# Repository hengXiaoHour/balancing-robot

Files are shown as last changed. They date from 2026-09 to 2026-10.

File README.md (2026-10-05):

# Balancing Robot






Self-balancing two-wheel robot on ESP32 + L298N + MPU IMU, with a serial
setup wizard, WiFi Web UI (telemetry + PID tuning), and optional ESP-NOW
joystick control. Runtime-configurable: pins, WiFi, IMU, and PID all live
in NVS via the serial CLI — `settings.h` holds seed defaults only.

> Built for real hardware: dual angle PID @ 1 kHz, Madgwick fusion, NVS-persisted
> config, embedded Web UI served from flash, OTA-ready. See `firmware/ARCHITECTURE.md`
> for the module map.

## Hardware

- Board: ESP32-C3 by default (ESP32 / ESP32-S3 selectable in `settings.h`)
- IMU: auto-detect — MPU6050 (I2C) or MPU6500 (SPI / I2C)
- Drivers: L298N dual H-bridge, N20 motors
- Filter: Madgwick (Kalman, Mahony, EKF, Complementary selectable)
- Control: dual angle PID @ 1 kHz, optional cascade angle+rate mode
- Printable chassis + N20 mounts in `assets/balancing_robot_STL/`

## Setup

1. Open `firmware/balancing_robot/balancing_robot.ino` in Arduino IDE.
   Install ESP32 core plus `WebSocketsServer` (Markus Sattler) and
   `ArduinoOTA` via the Library Manager.
2. In `src/config/settings.h` pick your board (`ACTIVE_BOARD`) and IMU
   (`ACTIVE_IMU`, 0 = auto-detect). Leave `WIFI_SSID` / `WIFI_PASSWORD`
   as placeholders — real credentials go in over serial, never in git.
3. Flash at 115200 baud, then open the Serial Monitor and run `setup`.
   The wizard walks through pins, IMU, motor, LED, link, WiFi, and
   calibration in 7 steps (`setup <step>` jumps straight to one).
4. Set WiFi without touching code: `wifi set ssid <name>`,
   `wifi set pass <password>`, then `wifi save`. Check with `wifi show`
   (passwords stay masked) and `wifi_status`.
5. In Arduino IDE set Tools → Partition Scheme to "No FS 4MB (2MB APP x2)"
   (the default 1.2MB app partition is too small for the embedded Web UI).
6. Connect to the same network — or to the robot's own `ESP32_BALANCING`
   AP — and open `http://<robot-ip>/` (AP mode: `http://192.168.4.1/`)
   for the Web UI (live attitude, battery, arm switch, stick control).
   Telemetry/tuning runs over WebSocket port 81.
7. Tune the balance: start with `DEFAULT_KP_PITCH` / `KI` / `KD` in
   `settings.h`, or live via serial (`pp` / `pi` / `pd` …) or the Web UI —
   every change auto-saves to NVS. `load` reloads saved values,
   `reset_pid` returns to compiled defaults.

Handy serial commands: `status`, `load`, `reset_pid`, `i2c_scan`,
`abort setup`, `reboot`. Type `help` on the robot for the full list.

## Web UI

Dark HUD theme, four tabs. Served by the robot itself on port 80 —
the UI (HTML/CSS/JS/fonts/uPlot) is embedded in the firmware flash via
`tools/gen_web_assets.py` → `src/web/web_assets.h`. No phone-side file or
internet connection needed once the phone is on the robot's WiFi. Re-run
`python3 firmware/balancing_robot/tools/gen_web_assets.py` after editing
anything under `UI/`, then recompile.

CONTROL — square stick, live pitch/roll/yaw, arm bar:

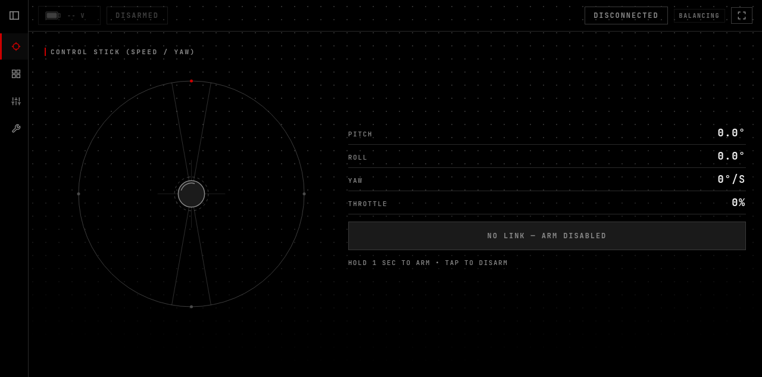
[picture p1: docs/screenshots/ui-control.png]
CONTROL tab


STATUS — link, battery, IMU, motors:

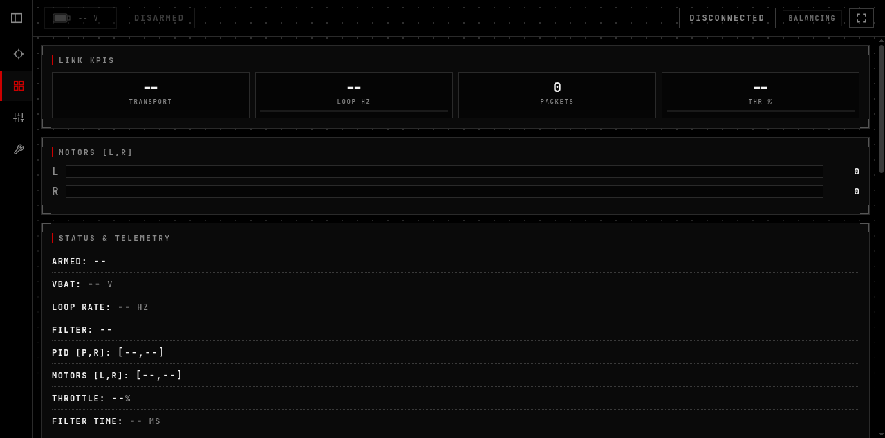
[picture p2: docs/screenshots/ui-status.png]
STATUS tab


PID TUNE — pitch/roll/yaw gains, load + reset:

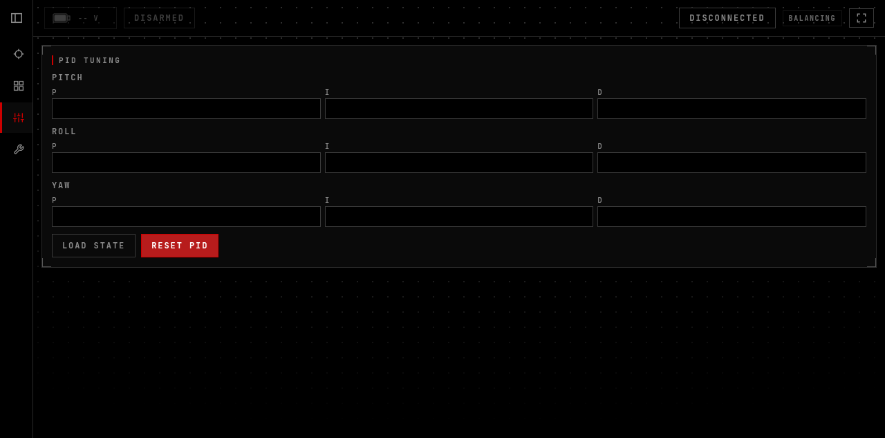
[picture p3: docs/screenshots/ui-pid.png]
PID TUNE tab


SETUP — vehicle, connection, stick range, calibration:

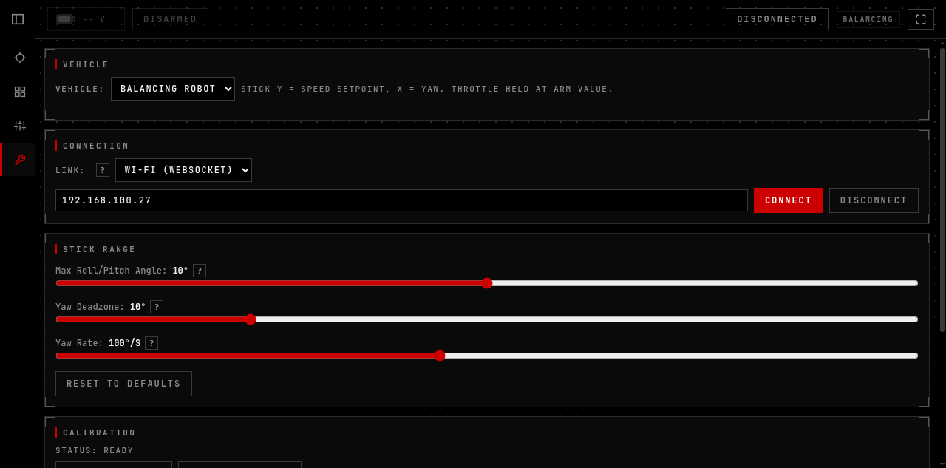
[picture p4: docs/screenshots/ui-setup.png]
SETUP tab


## Layout

- `firmware/balancing_robot/` — Arduino sketch (`src/config`, `sensors`,
  `filters`, `control`, `comms`, `system`, `utils`; see
  `firmware/ARCHITECTURE.md`)
- `UI/` — Web UI (index.html + css/js), served by the robot on :80
- `assets/balancing_robot_STL/` — chassis + motor mount STLs

## Notes

- `settings.h` in git carries placeholder WiFi/MAC values on purpose.
  Keep it that way — `git add` files explicitly, never `git add -A`.
- Default AP mode: SSID `ESP32_BALANCING`, password `balancing123`.
  Change it on your board over serial (`wifi set ap_pass <yours>` +
  `wifi save`) before taking the robot to public places.

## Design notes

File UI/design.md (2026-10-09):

# UI Design System — Balancing Robot WebUI

> Extracted from `UI/css/*.css` + `UI/index.html`. Single source of truth for visual patterns.
> Theme origin: Stitch NEBULA VOID export (`UI/stitch_store_llm_store_page_redesign.zip`, reference only, untracked).

---

## 1. Design Language

**Aesthetic**: NEBULA VOID military terminal — pure black base, bone-white text, hairline gray borders, single blood-red action accent, teal reserved for live/connected status. Zero rounded corners, zero shadows, zero blur. Flat data plates, not floating cards.

**Motion**: Linear 0.2s width transitions on sidebar. No bounce, no glow pulses (field tool, not a storefront).

---

## 2. Color Palette

All colors are CSS custom properties in `:root` (`UI/css/theme.css:3-15`).

| Token | Value | Usage |
|---|---|---|
| `--bg` | `#000000` | Page background, deepest layer |
| `--surface` | `#0A0A0A` | Cards, panels, sidebar hover |
| `--border` | `#2A2A2A` | All hairline borders and dividers |
| `--ghost-border` | `#3A3A3A` | Ghost button outlines, input borders |
| `--text` | `#F2F2F2` | Headings, values, primary text |
| `--muted` | `#8A8A8A` | Labels, hints, secondary text |
| `--red` | `#CC0000` | Primary actions, ARM/armed, active nav |
| `--red-hot` | `#FF0A0A` | Critical highlights, ARM hover, brand span |
| `--teal` | `#00E5CC` | Connected status, live telemetry values, console text |

**Rules**:
- Red = something you can tap to do something, or where you are. Never decorative.
- Teal = system-is-live (connected pill, telemetry numbers, console). Never competes with red in the same element.
- Disconnected/idle = muted gray ghost. No color until it matters.
- Global `* { border-radius: 0 !important; }` (`theme.css:17`). Square corners everywhere.

---

## 3. Typography

Loaded in `UI/index.html` head from Google Fonts with system fallback.

| Font | Stack | Usage |
|---|---|---|
| Display | `'Oswald', 'Anton', 'Arial Narrow', sans-serif` (`--font-display`) | h1/h2/h3, brand, sidebar labels. Uppercase, letter-spacing 0.08em |
| Mono | `'JetBrains Mono', 'Space Mono', monospace` (`--font-mono`) | Body default, labels, telemetry, buttons, inputs, console. Uppercase, letter-spacing 0.12–0.16em, 11–13px |

Hierarchy is size + weight + tracking, not color. Labels are muted 11px mono tracked out; values are larger white or teal.

---

## 4. Spacing & Layout

**Desktop**: left icon rail + top header bar + scrollable content column (`.app` flex row, `theme.css:34-37`).
**Mobile** (`@media max-width: 768px`): sidebar becomes a fixed bottom tab bar (row, red top indicator on active), panels stack single-column, PID grid collapses to 1 column, header shrinks to 12px, content pads above the tab bar with safe-area insets.
**Touch targets**: min 44px height on all buttons, selects, inputs, nav items (mobile only, `theme.css:115-121`).
**Card padding**: 14px. Section gap: 12px. Max content width: unconstrained (tool UI, fills viewport).

---

## 5. Components

### 5.1 Sidebar (48px collapsed / 260px expanded)
- `UI/css/sidebar.css:2-13` — Left rail, pure black, 1px right hairline, always visible on desktop.
- Hamburger toggle row (`14px 12px` padding), display font, uppercase.
- Nav items: full-width, `10px 12px` padding, 3px transparent left bar, muted 12px mono 700 uppercase labels with 24px icon slot.
- Hover: surface bg + white text. Active: surface bg + red-hot text + red left bar (`sidebar.css:59-63`).
- Mobile: same markup becomes fixed bottom bar via CSS only — row direction, icon-over-label, red top indicator, toggle/spacer hidden (`theme.css:123-166`).

### 5.2 Header data plate
- `UI/css/panels.css:1-21` — Flat black bar, bottom hairline. Single row everywhere:
  battery indicator, link pill (flex-1 middle stretch), 44x44 fullscreen square right.
  The old ARM pill + BALANCING badge are gone (arm lives on CONTROL's hold button).
- Connection pill: ghost outline; connected = teal text/border, disconnected = muted gray (`panels.css:33-35`).
- Battery indicator: black plate, hairline border, mono 11px uppercase (`panels.css:56-69`).
- Header (mobile): one nowrap row, every item 44px tall; fullscreen is a 44x44 square pinned right (`panels.css` mobile block).
- Fullscreen on a phone: header gains `max(28px, safe-area)` top padding so the
  hole-punch camera never covers it; normal view untouched (`:fullscreen` rule).

### 5.3 Buttons
- Primary (`button.control-btn`): solid `#CC0000` fill, white 12px mono 700 uppercase, 0.16em tracking, `8px 14px` padding. Hover: red-hot. Disabled: ghost + muted (`theme.css:56-70`).
- Secondary/ghost (`.secondary`, `#fullscreenBtn`, `.console-clear-btn`): transparent fill, 1px ghost border, muted text. Hover: white text + white border.
- Range inputs: red accent-color, full width (`theme.css:54`).

### 5.4 Telemetry data plates
- `.card`: surface bg, 1px border, 14px padding (`panels.css:71-77`). Card titles display 14px white uppercase; subtitles muted mono 12px.
- `.telemetry-item`: hairline bottom divider, muted uppercase micro-label, white `<strong>`, teal live `<span>` values (`panels.css:106-110`).
- Header (mobile): two even rows, every pill 44px tall; fullscreen is a 44x44 square pinned right (`panels.css` mobile block).

### 5.5 Joystick instrument
- `UI/css/stick.css` — `#joystick1` black plate, 1px border, crosshair cursor, 280px desktop / 240px mobile height, full-width `100dvh`-derived height on small phones (`stick.css:39-47`).
- Landscape phone (incl. fullscreen): side-by-side grid — stick sized to the short
  viewport (`minmax(150px, 100dvh-200px)`) with readout + arm beside it, no scroll.
  Link pill right-packs next to the fullscreen icon (`margin-left: auto`).
- Portrait CONTROL fills the column (flex `space-evenly`) so the arm button lands
  just above the tab bar instead of floating mid-screen.
- Text-select bug fix baked in: `user-select: none`, `-webkit-touch-callout: none`, `touch-action: none`, `overscroll-behavior: none` on wrap + canvas; JS uses preventDefault + `{ passive: false }` + touchcancel + contextmenu block (`UI/js/stick.js`).
- Readout rows: Pitch / Roll / Yaw only. The quadcopter-era Throttle row, THR % KPI
  and telemetry Throttle row are removed; `state.throttle` is still held and sent.

### 5.6 Console
- `#serialConsole`: black plate, hairline border, 180px scroll region, 11px mono teal text (`panels.css:125-136`).
  Lines carry NO timestamps (they ate a third of every phone line); typed `>>>`
  echoes render bold white (`.out`), errors red. Wrapping is `overflow-wrap:
  anywhere` with a hanging indent — `break-all` chopped words mid-glyph.
- Console input row (`.console-input-row`): Arduino-IDE-monitor input — text field
  (44px) + red Send; Enter sends too. USB serial writes the raw line; Wi-Fi sends
  `{"cli"}` and the firmware runs it through the real CLI dispatcher, streaming
  replies back as console frames. Firmware side: `src/comms/cli_tee.h` (a `Print`
  tee — USB always, plus WS while serving a line; it forwards to the real
  Serial device, CDC or UART, so both build configs work),
  `queueWsCliLine` drained in loop context, `cliConsoleOut` sanitizes + escapes
  JSON per line. `{"cli"}` is parsed next to the reboot handler.

### 5.7 Graph + gauges
- `#angleChart`: full width, CSS-box height (300px desktop / 260px mobile, JS sizes
  from `clientHeight` — a hardcoded height overflowed tick labels into the legend).
  Legend muted mono uppercase (`panels.css:152-165`), 12px gap, chart clips overflow.
- Y locked to ±20° (`auto: false`): tumbles clip at the rail, never rescale. No Auto Zoom.
  X axis hidden (`{ show: false }`) — wall-clock seconds fragments (`:10`, `:15`)
  are meaningless on a 10s rolling window.
- Attitude/compass canvases: black square plates, hairline border, wrap in flex row that stacks on mobile (`panels.css:167-170`).

### 5.8 Forms (PID / trim / settings)
- 3-column PID grid (1 column on mobile). Inputs: black fill, ghost border, mono 12px uppercase; focus border turns red (`theme.css:43-53`).

---

## 6. File Map

| File | Lines | Owns |
|---|---|---|
| `UI/index.html` | ~250 | Shell markup, sidebar/header/panels, css/js/manifest links, font links |
| `UI/css/theme.css` | ~167 | Tokens, reset, buttons, inputs, error bar, mobile tab-bar + touch rules |
| `UI/css/sidebar.css` | ~80 | Rail, toggle, nav items, active states |
| `UI/css/panels.css` | ~186 | Header (one-line), pills, battery, cards, telemetry, PID, console, graph, gauges |
| `UI/css/stick.css` | ~47 | Joystick plate, readout, phone sizing |
| `UI/js/state.js` | ~84 | State object, fixed balancing vehicle, settings |
| `UI/js/link.js` | ~193 | WebSocket connect/reconnect, message parse, telemetry render, console |
| `UI/js/stick.js` | ~112 | Stick canvas, balancing-robot mapping, select-bug fix listeners |
| `UI/js/panels.js` | ~385 | Panel switching, PID/trim/calibration actions, gauges, battery, fullscreen |
| `UI/manifest.webmanifest` | ~10 | Install metadata: fullscreen, landscape |

Rules: plain `<script>` tags in dependency order (no modules, works over file://). Element ids are the JS contract — rename in both or neither. WS message shapes must match `firmware/balancing_robot/src/comms/websocket_handler.cpp`.

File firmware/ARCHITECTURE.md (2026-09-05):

# Firmware Architecture — Balancing Robot

Arduino sketch + `src/` layout (required: the Arduino builder only
compiles `.cpp` files under the sketch `src/` directory).

- `balancing_robot.ino` (~460 lines): includes, all global variable
  definitions, `setup()`, `loop()`. No logic lives here anymore —
  every function body has moved into `src/`.

## `src/config/` — compile-time configuration
- `config.h`: PID defaults (single source of truth), pins, thresholds,
  loop rates, feature flags (`ENABLE_CASCADE_PID`, `ENABLE_ESPNOW`).
- `board.h`: board-specific pin map. `sensor.h`: IMU profile selection
  (`IMU_Custom` alias for MPU6050 / MPU6500 I2C / SPI).

## `src/sensors/` — hardware drivers
- `MPU6050_Custom`, `MPU6500_I2C_Custom`, `MPU6500_SPI_Custom`
  (`.h`/`.cpp` pairs), `calibration.h/.cpp` (NVS bias storage),
  `battery_state.h` (`BatteryState` enum shared by battery + comms).

## `src/filters/` — attitude estimation (select ONE)
- `filter_selector.h`: uncomment one `USE_*_FILTER` define.
- Kalman, Mahony, Madgwick (active), Complementary (2D),
  Complementary-Quaternion (3D), EKF — each a `.h`/`.cpp` pair sharing
  the `pitch`/`roll`/`yaw` globals. `getActiveFilterName()` is `inline`.

## `src/control/` — PID + motors
- `pid_controller.h/.cpp`: single-PID pitch/roll/yaw, `applyBraking()`,
  `updateDualPID()`. `cascade_pid_controller.h/.cpp`: outer angle +
  inner rate loops. `motor_control.h/.cpp`: 2-motor PWM mix
  (`updateVehicleMotorControl()`), input limits, `initVehicleMotors()`.

## `src/comms/` — outside world
- `serial_commands.h/.cpp`: USB CLI (`status`, `load`, `save`, `i2c_scan`…).
- `wifi_ota.h/.cpp`: WiFi + OTA. NOTE: real SSID/password live in
  `src/config/settings.h` **uncommitted, local-only** — HEAD carries placeholders.
- `websocket_handler.h/.cpp`: WebSocket server on :81 (telemetry out,
  PID tuning in). `esp_now_handler.h/.cpp`: ESP-NOW joystick input.

## `src/system/` — cross-cutting runtime pieces (Phase 5)
- `prefs.h/.cpp`: PID save/load/reset via NVS (`Preferences`).
- `battery.h/.cpp`: voltage filtering + low-voltage LED logic.
- `imu.h/.cpp`: global `mpu` object + `initIMU()`.
- `control_task.h/.cpp`: the 1 kHz `controlLoopTask` (Core 0).

## `src/utils/`
- `timing.h/.cpp`: loop-time stats. `i2c_scan.h/.cpp`: bus scan helper.

## Conventions
- One `.h`/`.cpp` pair per module; shared state via `extern` in the
  header, defined once in the `.ino` (globals) or the `.cpp` (module
  objects like `mpu`). Include order: `config.h` first.
- WiFi creds never committed. `git add` explicitly — never `git add -A`.

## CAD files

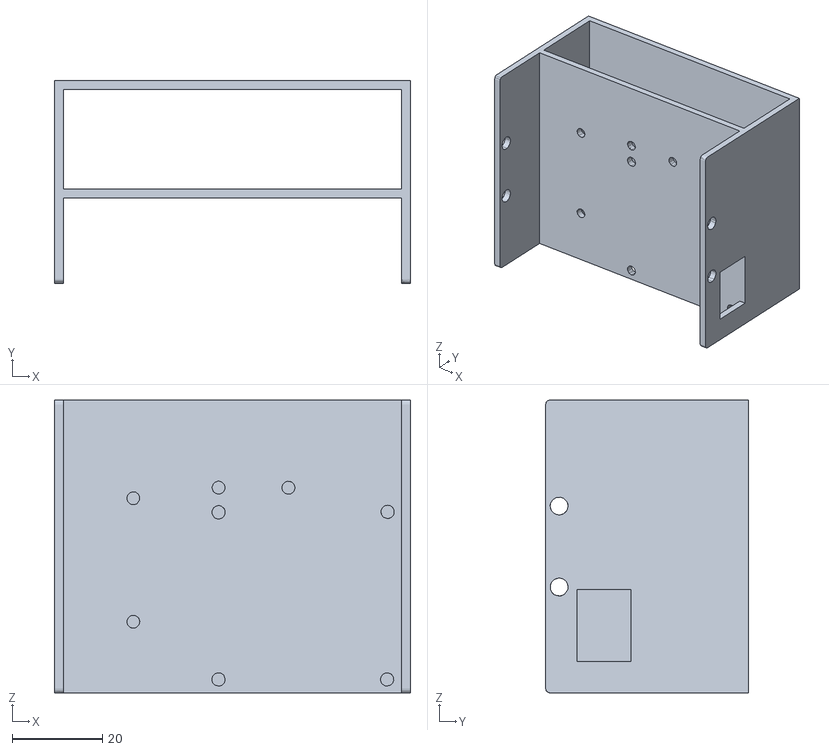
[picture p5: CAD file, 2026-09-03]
assets/balancing_robot_STL/chassis.stl
79.0 x 45.0 x 65.0

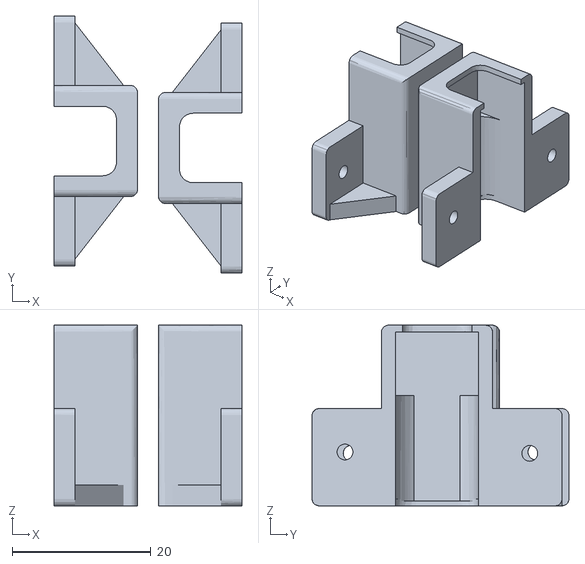
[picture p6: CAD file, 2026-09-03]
assets/balancing_robot_STL/n20 motor mount.stl
27.0 x 37.0 x 26.0

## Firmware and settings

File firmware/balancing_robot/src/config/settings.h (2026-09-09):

#ifndef SETTINGS_H
#define SETTINGS_H

// ============================================================
// BALANCING ROBOT — USER SETTINGS
// ============================================================
// THE ONLY FILE YOU NEED TO EDIT. Two selectors below retarget
// the whole firmware; everything else is tuning values.
//   board_pins.h / imu_select.h → parts bins (do not edit)
//   axis_map.h                  → macro machinery (do not edit)
// ============================================================

// ===== HARDWARE SELECTORS =====
#define ACTIVE_BOARD 2  // 1=ESP32, 2=ESP32-C3, 3=ESP32-S3
#define ACTIVE_IMU   0  // 0=auto-detect (SPI first, then I2C by WHO_AM_I), 1=MPU6050 (I2C), 2=MPU6500 (SPI), 3=MPU6500 (I2C)

#include "board_pins.h"
#include "imu_select.h"

// ===== CONTROL MODE =====
#define ENABLE_CASCADE_PID 0  // 1 = cascade (angle + rate), 0 = dual angle PID

// ===== PID GAINS (single source of truth — boot + reset agree) =====
// Each axis seeds its own NVS keys at boot/reset; live values diverge after tuning.
// Pitch is the balancing axis; roll forced straight, yaw runs rate mode.
// NOTE: NVS still holds stale legacy "KP"/"KI"/"KD" keys from older builds —
// harmless leftovers, never read by this firmware.

// Pitch axis seeds (the balance axis — tune here first)
#define DEFAULT_KP_PITCH 8.0
#define DEFAULT_KI_PITCH 0.2
#define DEFAULT_KD_PITCH 5.0

// Roll axis seeds (roll output forced off on balancing robot)
#define DEFAULT_KP_ROLL 8.0
#define DEFAULT_KI_ROLL 0.2
#define DEFAULT_KD_ROLL 5.0

// Yaw axis seeds (yaw runs rate mode, deg/s)
#define DEFAULT_KP_YAW 8.0
#define DEFAULT_KI_YAW 0.2
#define DEFAULT_KD_YAW 5.0

// ===== CASCADE PID (only used if ENABLE_CASCADE_PID = 1) =====
#define CASCADE_MODE_ANGLE_CONTROL 1  // 1 = angle mode, 0 = direct rate mode
#define CASCADE_MAX_RATE_SETPOINT 90.0f
#define CASCADE_RATE_INTEGRAL_LIMIT 200
#define CASCADE_ANGLE_INTEGRAL_LIMIT 100

// Cascade gain seeds (dormant while ENABLE_CASCADE_PID = 0; tune when enabling).
// cascade_pid_controller.h keeps #ifndef fallbacks that defer to these.
// Pitch outer angle loop
#define CASCADE_PITCH_ANGLE_KP 0.0
#define CASCADE_PITCH_ANGLE_KI 0.0
#define CASCADE_PITCH_ANGLE_KD 0.0
// Pitch inner rate loop (inner response: raise toward 50->120 for rate-mode responsiveness)
#define CASCADE_PITCH_RATE_KP 0.0
#define CASCADE_PITCH_RATE_KI 0.0
#define CASCADE_PITCH_RATE_KD 0.0
// Roll outer angle loop
#define CASCADE_ROLL_ANGLE_KP 0.0
#define CASCADE_ROLL_ANGLE_KI 0.0
#define CASCADE_ROLL_ANGLE_KD 0.0
// Roll inner rate loop
#define CASCADE_ROLL_RATE_KP 0.0
#define CASCADE_ROLL_RATE_KI 0.0
#define CASCADE_ROLL_RATE_KD 0.0

#define PID_MAX 4095           // Maximum PID output (motor speed limit)
#define PID_INTEGRAL_LIMIT 500  // Integral windup protection
#define PID_CONTROL_LOOP_HZ 1000  // Control loop frequency in Hz

// ===== BALANCING ROBOT INPUT SAFETY LIMITS =====
#define ROBOT_MAX_PITCH_SETPOINT_DEG 10.0f  // Firmware hard cap; UI maxAngle (default 10) stays under this
#define ROBOT_PITCH_INPUT_DEADBAND_DEG 0.6f
#define ROBOT_YAW_INPUT_DEADBAND 0.10f
#define ROBOT_MAX_ACTUAL_TILT_DEG 7.0f
#define ROBOT_TILT_GUARD_BAND_DEG 1.0f
#define ROBOT_SETPOINT_SLEW_DEG_PER_S 300.0f  // Max setpoint change rate

// ===== ESP-NOW JOYSTICK DEADZONES (raw ADC, stick ±2048) =====
#define ESPNOW_PITCH_DEADZONE 200
#define ESPNOW_ROLL_DEADZONE 200
#define ESPNOW_YAW_DEADZONE 1000

// ===== JOYSTICK YAW TOGGLE (1 = yaw stick active, 0 = forced zero) =====
#define JOYSTICK_YAW_INPUT_ENABLED 1

// ===== CONTROLLER INPUT SIGN (-1.0f reverses an axis) =====
#define CONTROLLER_PITCH_SIGN -1.0f
#define CONTROLLER_ROLL_SIGN 1.0f  // NOT USED: roll disabled
#define CONTROLLER_YAW_SIGN -1.0f

// ===== AXIS INVERSION (0 = normal, 1 = invert; consumed by axis_map.h) =====
#define ROLL_AXIS_INVERT 0   // NOT USED: roll disabled
#define PITCH_AXIS_INVERT 0
#define YAW_AXIS_INVERT 0    // Set to 1 to reverse yaw joystick input
#define GYRO_X_INVERT 0
#define GYRO_Y_INVERT 0
#define GYRO_Z_INVERT 0

// ===== FAILSAFE + CALIBRATION =====
#define FAILSAFE_ANGLE 60.0   // Auto-disarm if tilt exceeds this (deg)
#define CALIBRATION_SAMPLES 200  // Samples per calibration step

// ===== LOOP TIMING =====
#define LOOP_INTERVAL 1   // ms (1 = 1000Hz, 2 = 500Hz, 10 = 100Hz)
#define PID_UPDATE_PAUSE 5000  // ms to pause telemetry after a PID change

// ===== SERIAL =====
#define SERIAL_BAUD 115200  // Must match your serial monitor setting

// ===== WIFI (STA + AP + OTA) — sole WiFi config, consumed by comms/wifi_ota.h =====
// NOTE: real credentials live only in the local working copy, never in git.
#define WIFI_SSID "YOUR_WIFI_SSID"
#define WIFI_PASSWORD "YOUR_WIFI_PASSWORD"
#define AP_SSID "ESP32_BALANCING"      // Access Point name when in AP mode
#define AP_PASSWORD "balancing123"  // Access Point password (change via `wifi set ap_pass`)

// ===== FILTER PARAMETERS =====
#define GYRO_LPF_ALPHA 1.0f       // Gyroscope software low-pass
#define ACCEL_LPF_ALPHA 0.1f      // Accelerometer software low-pass
#define BATTERY_LPF_ALPHA 0.15f   // Battery voltage low-pass
#define TIME_ALPHA 0.1            // Timing measurement smoothing
#define FAILSAFE_LPF_ALPHA 0.2    // Failsafe angle detection filter
#define SAFE_ANGLE_THRESHOLD 40.0f       // Arm when angle below this (deg)
#define SAFE_ANGLE_HYSTERESIS_CHECKS 10  // Consecutive safe readings to arm

// ===== DEBUG & MONITORING =====
#define ENABLE_DEBUG_PRINTS 1  // 1 = debug output, 0 = saves CPU/flash
#define TELEMETRY_UPDATE_RATE 100  // Telemetry print interval in ms

// ===== CONTROL PROTOCOL (only ONE main protocol: serial XOR websocket XOR esp-now) =====
#define ENABLE_SERIAL_COMMANDS_AND_STATUS 1  // Serial CLI + status
#define ENABLE_WEBSOCKET_CONTROL 1           // Web UI (conflicts with ESP-NOW)
#define ENABLE_ESPNOW 0                      // Wireless controller (works with serial)

// ===== ESP-NOW =====
#define ESPNOW_UPDATE_RATE 20    // Update interval in ms (50 Hz)
#define ESPNOW_TIMEOUT 2000      // Connection timeout in ms (failsafe)
#define ESPNOW_RSSI_TIMEOUT 2000  // RSSI ACK timeout in ms

// Controller MAC address (your transmitter — set to your controller's MAC)
#define CONTROLLER_MAC_0 0xAA
#define CONTROLLER_MAC_1 0xBB
#define CONTROLLER_MAC_2 0xCC
#define CONTROLLER_MAC_3 0xDD
#define CONTROLLER_MAC_4 0xEE
#define CONTROLLER_MAC_5 0xFF

// ESP-NOW setpoint limits (WS pitch shares ESPNOW_MAX_PITCH parse cap)
#define ESPNOW_MAX_PITCH 15.0f
#define ESPNOW_MAX_ROLL 12.0f
#define ESPNOW_MAX_YAW_RATE 100.0f

// ===== IMU RANGES =====
#define ANGLE_WRAP_ENABLED 1  // Wrap angles to ±180°
#define ACCEL_RANGE_G 2       // ±2G, ±4G, ±8G, or ±16G
#define AZ_SIGN 1  // 1 = descend positive, 0 = inverted

// ===== MOTOR BALANCE TRIM (0.8–1.2 if one motor is stronger) =====
#define MOTOR_LEFT_SPEED_MULTIPLIER 1.0
#define MOTOR_RIGHT_SPEED_MULTIPLIER 1.0

// ===== STARTUP BEHAVIOR =====
#define AUTO_LOAD_PID 1               // Auto-load PID from NVS
#define AUTO_LOAD_CALIBRATION 0       // Auto-load calibration from NVS
#define PRINT_CALIBRATION_ON_STARTUP 0  // 1 = dump loaded cal values at boot (noisy); 0 = quiet boot

// Axis-mapping machinery derives from the INVERT flags above.
#include "axis_map.h"

#endif  // SETTINGS_H

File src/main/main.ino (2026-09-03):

// Balancing Robot with Multiple Filtering Methods for Control Theory Study
// ESP32 + L298N mosfet Motor Driver + MPU6050
// Supports: Kalman, Mahony, Madgwick, Complementary Filters

#include <Wire.h>
#include <Preferences.h>
#include "config/config.h"  // Load all configuration parameters

// Preference storage
Preferences prefs;

// PID Controller Variables (loaded from preferences)
float KP = DEFAULT_KP;
float KI = DEFAULT_KI;
float KD = DEFAULT_KD;

// Include header files AFTER config.h
#include "filters/filter_selector.h"        // Filter selection (choose ONE)
#include "control/motor_control.h"
#include "filters/kalman_filter.h"
#include "filters/mahony_filter.h"
#include "filters/madgwick_filter.h"
#include "filters/complementary_filter.h"
#include "filters/complementary_quaternion_filter.h"
#include "filters/ekf_filter.h"
#include "control/pid_controller.h"
#if ENABLE_CASCADE_PID
#include "control/cascade_pid_controller.h"  // Cascade PID with unified gains
#endif
#include "sensors/calibration.h"
#include "utils/timing.h"

// ===== Battery Low Voltage Monitoring =====
#define LOW_VOLTAGE_THRESHOLD 3.5f  // Voltage threshold for low battery detection
enum BatteryState {
  BATTERY_NORMAL,        // Normal operation
  BATTERY_LOW_CONFIRMED  // Low battery detected - LED blinking
};

// ESP-NOW throttle gating variables (declared before includes so esp_now_handler.h can use them)
bool throttle_gate_ready = false;  // Throttle gating for ESP-NOW
float last_throttle = 0.0f;        // Previous throttle value for ESP-NOW gating

#include "comms/serial_commands.h"
#include "comms/wifi_ota.h"  // WiFi + OTA support
#include "comms/websocket_handler.h"  // WebSocket server and communication
#include "comms/esp_now_handler.h"  // ESP-NOW controller communication

// External variables from ESP-NOW handler
extern volatile bool espnow_connected;

// Calibration state
CalibrationState calibrationState = CALIB_IDLE;

// Global IMU object
IMU_Custom mpu;
// ===== GLOBAL VARIABLE DECLARATIONS (Core Control Variables) =====

// MPU6050 initialization status
bool mpuInitialized = false;

// Calibration bias values from preferences
float gyroBiasX = 0.0f;
float gyroBiasY = 0.0f;
float gyroBiasZ = 0.0f;
float axBias = 0.0f;
float axScale = 1.0f;
float ayBias = 0.0f;
float ayScale = 1.0f;
float azBias = 0.0f;
float azScale = 1.0f;

// Global Variables
unsigned long lastLoopTime = 0;
bool filterInitialized = false;
bool motorsArmed = false;
bool motorsActive = false;
bool statusMonitoring = false;
bool debugMonitoring = false;
float pitch_setpoint = 0.0;
float roll_setpoint = 0.0;
float yaw_setpoint = 0.0;

// Sensor variables
int16_t accelX, accelY, accelZ;
int16_t gyroX, gyroY, gyroZ;

// Raw MPU data
int16_t mpu_accelX, mpu_accelY, mpu_accelZ;
int16_t mpu_gyroX, mpu_gyroY, mpu_gyroZ;

// Attitude filter variables
float pitch = 0.0, roll = 0.0, yaw = 0.0;
float pitch_final = 0.0, roll_final = 0.0;
float pitch_bias = 0.0, roll_bias = 0.0, yaw_bias = 0.0;
float trim_pitch = 0.0;
float trim_roll = 0.0;
float P[6][6] = {
  {1, 0, 0, 0, 0, 0},
  {0, 1, 0, 0, 0, 0},
  {0, 0, 1, 0, 0, 0},
  {0, 0, 0, 1, 0, 0},
  {0, 0, 0, 0, 1, 0},
  {0, 0, 0, 0, 0, 1}
};
float dt = 0.02;

// PID variables
float pidError = 0.0;
float pidIntegral = 0.0;
float pidLastError = 0.0;
float pidOutput = 0.0;

// DUAL PID - PITCH
float pidError_Pitch = 0.0;
float pidIntegral_Pitch = 0.0;
float pidOutput_Pitch = 0.0;
float KP_Pitch = DEFAULT_KP;
float KI_Pitch = DEFAULT_KI;
float KD_Pitch = DEFAULT_KD;

// DUAL PID - ROLL
float pidError_Roll = 0.0;
float pidIntegral_Roll = 0.0;
float pidOutput_Roll = 0.0;
float KP_Roll = DEFAULT_KP;
float KI_Roll = DEFAULT_KI;
float KD_Roll = DEFAULT_KD;

// YAW AXIS
float pidIntegral_Yaw = 0.0;
float pidOutput_Yaw = 0.0;
float KP_Yaw = DEFAULT_KP;
float KI_Yaw = DEFAULT_KI;
float KD_Yaw = DEFAULT_KD;

// Cascaded control
float vel_x = 0.0f;
float vel_y = 0.0f;
float speed_x_setpoint = 0.0f;
float speed_y_setpoint = 0.0f;
float speedKp = 0.1f, speedKi = 0.01f, speedKd = 0.0f;
float speedIntegral_x = 0.0f, speedIntegral_y = 0.0f;
float speedDeadband = 0.05f;
float maxAngleFromSpeed = 5.0f;
float accel_x_filtered = 0.0f, accel_y_filtered = 0.0f;
float accelAlpha = 0.1f;
float velDecay = 0.9f;
float yaw_rate_target = 0.0f;
float pitch_rate_target = 0.0f;
float roll_rate_target = 0.0f;
float LOW_THROTTLE_THRESHOLD = 15.0f;

// Motor scaling
float motorScale_Left = 1.0f;
float motorScale_Right = 1.0f;
float throttle = 25.0f;
float throttle_increment = 5.0f;
float throttle_input_normalized = 0.0f;

// Motor test mode
const float TEST_MOTOR_THROTTLE_PERCENT = 20.0f;
const unsigned long TEST_MOTOR_DURATION_MS = 2000;
bool testMotorActive = false;
int testMotorIndex = 0;
int testMotorLastPrinted = -1;
unsigned long testMotorStartMs = 0;

// Filter variables
float filtered_accelX = 0.0, filtered_accelY = 0.0, filtered_accelZ = 0.0;
float filtered_gyroX = 0.0, filtered_gyroY = 0.0, filtered_gyroZ = 0.0;

// Battery voltage monitoring
float battery_voltage = 0.0f;
float battery_voltage_filtered = 0.0f;
float battery_samples[BATTERY_SAMPLE_SIZE] = {0};
int battery_sample_index = 0;
bool batteryFilterPrimed = false;
float lastValidBatteryRawVoltage = 0.0f;

BatteryState batteryState = BATTERY_NORMAL;
unsigned long lastLEDBlink = 0;
bool ledState = false;

// Motor PIDs
float pidOutput_Left = 0.0;
float pidOutput_Right = 0.0;

// Telemetry
unsigned long lastPIDUpdateTime = 0;

// Failsafe filtering
float filtered_pitch = 0.0;
float filtered_roll = 0.0;

// Arm hysteresis
bool safeToArm = false;
uint16_t safeAngleCounter = 0;

// Dual-core task variables
SemaphoreHandle_t dataLock = NULL;
volatile bool controlLoopRunning = false;
volatile unsigned long loopTimeMs = 0;

// Computational complexity tracking
volatile unsigned long filterExecutionTime = 0;
volatile uint32_t freeHeapMemory = 0;
volatile uint32_t minFreeHeap = 999999;
float avgFilterTime = 0.0;

// Barometer stubs (disabled but variables retained for NVS compatibility)
float baro_altitude_scale = 1.0f;
float accel_z_bias_cal_mps2 = 0.0f;
float accel_z_world_mps2 = 0.0f;
float vertical_velocity_mps = 0.0f;
float altitude_est_m = 0.0f;
bool altitudeHoldEnabled = false;

// ===== BATTERY VOLTAGE MANAGEMENT FUNCTIONS =====
void updateBatteryVoltage() {
  int adc_raw = analogRead(BATTERY_PIN);
  float raw_voltage = (adc_raw / (float)ADC_MAX) * ADC_REF_VOLTAGE * BATTERY_DIVIDER_RATIO;

  if (!batteryFilterPrimed) {
    for (int i = 0; i < BATTERY_SAMPLE_SIZE; i++) {
      battery_samples[i] = raw_voltage;
    }
    battery_voltage_filtered = raw_voltage;
    battery_voltage = raw_voltage;
    lastValidBatteryRawVoltage = raw_voltage;
    batteryFilterPrimed = true;
    return;
  }

  float raw_delta = raw_voltage - lastValidBatteryRawVoltage;
  float max_step_down = BATTERY_GLITCH_REJECT_V;
  float max_step_up = BATTERY_GLITCH_REJECT_V * 2.0f;
  if (raw_delta > max_step_up) {
    raw_voltage = lastValidBatteryRawVoltage + max_step_up;
  } else if (raw_delta < -max_step_down) {
    raw_voltage = lastValidBatteryRawVoltage - max_step_down;
  }
  lastValidBatteryRawVoltage = raw_voltage;
  
  battery_samples[battery_sample_index] = raw_voltage;
  battery_sample_index = (battery_sample_index + 1) % BATTERY_SAMPLE_SIZE;
  
  float voltage_sum = 0.0f;
  for (int i = 0; i < BATTERY_SAMPLE_SIZE; i++) {
    voltage_sum += battery_samples[i];
  }
  float voltage_average = voltage_sum / BATTERY_SAMPLE_SIZE;
  
  battery_voltage_filtered = (BATTERY_LPF_ALPHA * voltage_average) + ((1.0f - BATTERY_LPF_ALPHA) * battery_voltage_filtered);
  battery_voltage = battery_voltage_filtered;
  
  if (debugMonitoring) {
    static unsigned long lastDebugTime = 0;
    if (millis() - lastDebugTime >= 1000 && millis() < 10000) {
      Serial.print("[BATTERY DEBUG] Raw ADC: ");
      Serial.print(adc_raw);
      Serial.print(", Raw Voltage: ");
      Serial.print(raw_voltage, 3);
      Serial.print("V, Filtered: ");
      Serial.print(battery_voltage, 3);
      Serial.println("V");
      lastDebugTime = millis();
    }
  }
}

void updateBatteryMonitoring() {
  static unsigned long initStartTime = 0;
  if (initStartTime == 0) initStartTime = millis();
  
  if (battery_voltage < 3.0f || (millis() - initStartTime) < 2000) {
    digitalWrite(LOW_VOLTAGE_LED_PIN, LED_OFF_LEVEL);
    return;
  }
  
  static int lowVoltageCount = 0;
  
  if (debugMonitoring) {
    static unsigned long lastDebugTime = 0;
    if (millis() - lastDebugTime >= 2000 && millis() < 30000) {
      Serial.print("[LED DEBUG] ESP-NOW Connected: ");
      Serial.print(espnow_connected ? "YES" : "NO");
      Serial.print(", Battery State: ");
      Serial.print(batteryState == BATTERY_NORMAL ? "NORMAL" : "LOW");
      Serial.print(", LED should be: ");
      if (batteryState == BATTERY_LOW_CONFIRMED) {
        Serial.println("BLINKING");
      } else if (espnow_connected) {
        Serial.println("ON (connected)");
      } else {
        Serial.println("OFF (disconnected)");
      }
      lastDebugTime = millis();
    }
  }
  
  switch (batteryState) {
    case BATTERY_NORMAL:
      pinMode(LOW_VOLTAGE_LED_PIN, OUTPUT);
      
      if (espnow_connected) {
        digitalWrite(LOW_VOLTAGE_LED_PIN, LED_ON_LEVEL);
      } else {
        digitalWrite(LOW_VOLTAGE_LED_PIN, LED_OFF_LEVEL);
      }
      
      if (battery_voltage <= LOW_VOLTAGE_THRESHOLD) {
        lowVoltageCount++;
        if (lowVoltageCount >= 5) {
          batteryState = BATTERY_LOW_CONFIRMED;
          Serial.println("[BATTERY] LOW BATTERY DETECTED! Voltage has been 3.3V or below for 100ms. LED will blink until battery changed.");
          pinMode(LOW_VOLTAGE_LED_PIN, OUTPUT);
          lowVoltageCount = 0;
        }
      } else {
        lowVoltageCount = 0;
      }
      break;
      
    case BATTERY_LOW_CONFIRMED:
      unsigned long now = millis();
      if (now - lastLEDBlink >= 500) {
        ledState = !ledState;
        digitalWrite(LOW_VOLTAGE_LED_PIN, ledState ? LED_ON_LEVEL : LED_OFF_LEVEL);
        lastLEDBlink = now;
      }
      break;
  }
}
// ===== BALANCING ROBOT MODE FUNCTIONS===="

inline void toggleMotorTest() {
  Serial.println("[MODE] Motor test command is disabled in BALANCING_ROBOT mode");
}

inline void updateMotorTest() {
}

inline void applyVehicleInputLimits() {
  #if ENABLE_CASCADE_PID && !CASCADE_MODE_ANGLE_CONTROL
  // In rate mode, don't modify pitch_setpoint - let pitch_rate_target handle it
  roll_setpoint = 0.0f;  // Roll always disabled for balancing robot
  return;
  #endif
  
  // ===== ANGLE MODE: Apply pitch setpoint limits and slew-rate limiting =====
  float measured_pitch = PITCH_ANGLE_FINAL_USED;
  float raw_setpoint = constrain(pitch_setpoint, -ROBOT_MAX_PITCH_SETPOINT_DEG, ROBOT_MAX_PITCH_SETPOINT_DEG);

  roll_setpoint = 0.0f;

  // Soft guard: only block outward commands near/over tilt boundary.
  // Do NOT inject opposite recovery commands (can cause oscillation).
  float guarded_setpoint = raw_setpoint;
  float guard_start_pos = ROBOT_MAX_ACTUAL_TILT_DEG - ROBOT_TILT_GUARD_BAND_DEG;
  float guard_start_neg = -ROBOT_MAX_ACTUAL_TILT_DEG + ROBOT_TILT_GUARD_BAND_DEG;

  if (measured_pitch >= ROBOT_MAX_ACTUAL_TILT_DEG && guarded_setpoint > 0.0f) {
    guarded_setpoint = 0.0f;
  } else if (measured_pitch <= -ROBOT_MAX_ACTUAL_TILT_DEG && guarded_setpoint < 0.0f) {
    guarded_setpoint = 0.0f;
  } else {
    // Linearly attenuate outward command inside guard band.
    if (measured_pitch > guard_start_pos && guarded_setpoint > 0.0f) {
      float t = (ROBOT_MAX_ACTUAL_TILT_DEG - measured_pitch) / max(ROBOT_TILT_GUARD_BAND_DEG, 0.001f);
      t = constrain(t, 0.0f, 1.0f);
      guarded_setpoint *= t;
    } else if (measured_pitch < guard_start_neg && guarded_setpoint < 0.0f) {
      float t = (measured_pitch + ROBOT_MAX_ACTUAL_TILT_DEG) / max(ROBOT_TILT_GUARD_BAND_DEG, 0.001f);
      t = constrain(-t, 0.0f, 1.0f);
      guarded_setpoint *= t;
    }
  }

  // Slew-rate limit setpoint changes to avoid jerky PID excitation.
  static float limited_setpoint = 0.0f;
  float max_step = ROBOT_SETPOINT_SLEW_DEG_PER_S * dt;
  float delta = guarded_setpoint - limited_setpoint;
  delta = constrain(delta, -max_step, max_step);
  limited_setpoint += delta;

  pitch_setpoint = limited_setpoint;
}

inline void initVehicleMotors() {
  pinMode(IN1, OUTPUT);
  pinMode(IN2, OUTPUT);
  pinMode(IN3, OUTPUT);
  pinMode(IN4, OUTPUT);
  ledcAttach(ENA, PWM_FREQ, PWM_RES);
  ledcAttach(ENB, PWM_FREQ, PWM_RES);
  setLeftMotorSpeed(0.0f);
  setRightMotorSpeed(0.0f);
}
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
void loop() {
  // CORE 1: Handle all non-critical tasks (serial commands, telemetry, calibration UI)
  // Control loop runs uninterrupted on Core 0
  
  // TELEMETRY
  static unsigned long lastTelemetry = 0;
  if (statusMonitoring && (millis() - lastTelemetry >= TELEMETRY_UPDATE_RATE)) {
    lastTelemetry = millis();
    
    float loopRate = 1000000.0f / (loopTimeUs > 0 ? loopTimeUs : 1);
    
    Serial.print("[LOOP] ");
    Serial.print("[Filter: "); Serial.print(getActiveFilterName()); Serial.print("] | ");
    Serial.print("Mode: BALANCING_ROBOT | ");
    Serial.print("Status: "); Serial.print(motorsArmed ? "ARMED" : "DISARMED"); Serial.print(" | ");
    Serial.print("Rate: "); Serial.print(loopRate, 2); Serial.print("Hz | ");
    Serial.print("Pitch: "); Serial.print(PITCH_ANGLE_FINAL_USED, 2); Serial.print("deg | ");
    Serial.print("Roll: "); Serial.print(ROLL_ANGLE_FINAL_USED, 2); Serial.print("deg | ");
    Serial.print("Yaw: "); Serial.print(yaw, 2); Serial.print("deg | ");
    Serial.print("PID[P,R]: "); Serial.print(pidOutput_Pitch, 0); Serial.print(",");
    Serial.print(pidOutput_Roll, 0); Serial.print(" | ");
    Serial.print("Motors[L,R]: "); Serial.print(pidOutput_Left, 0); Serial.print(",");
    Serial.print(pidOutput_Right, 0); Serial.print(" | ");
    Serial.print("Vbat: "); Serial.print(battery_voltage, 2); Serial.print("V | ");
    Serial.print("Az: "); Serial.print(accel_z_world_mps2, 2); Serial.print("m/s2 | ");
    Serial.print("[COMP] Filter: "); Serial.print(filterExecutionTime); Serial.print("us (avg: ");
    Serial.print(avgFilterTime, 1); Serial.print("us) | Heap: "); Serial.print(freeHeapMemory);
    Serial.print("B (min: "); Serial.print(minFreeHeap); Serial.print("B) | Load: ");
    float cpuLoad = (avgFilterTime / 10000.0) * 100.0;
    Serial.print(cpuLoad, 1); Serial.println("%");
  }
  
  // Check for OTA updates (disabled when using ESP-NOW)
  #if !ENABLE_ESPNOW
  ArduinoOTA.handle();
  #endif
  
  // Handle WiFi connection in STA mode (disabled when using ESP-NOW)
  #if !ENABLE_ESPNOW
  handleWiFiConnection();
  #endif
  
  // Handle WebSocket server
  #if ENABLE_WEBSOCKET_CONTROL
  handleWebSocketLoop();
  #endif
  
  // Handle serial commands (don't block)
  #if ENABLE_SERIAL_COMMANDS_AND_STATUS
  handleSerialCommand();
  #endif

  updateMotorTest();

  // Barometer disabled - removed
  
  // Update ESP-NOW controller input
  #if ENABLE_ESPNOW
  updateESPNOWService();
  #endif
  
  // Update calibration if active (non-blocking on Core 1)
  if (calibrationState != CALIB_IDLE) {
    updateCalibration();
  }

  
  // Periodic MPU6050 initialization retry (every 30 seconds if not initialized)
  static unsigned long lastMPURetry = 0;
  if (!mpuInitialized && (millis() - lastMPURetry > 30000)) {
    lastMPURetry = millis();
    retryMPUInitialization();
  }
  
  // Small delay to prevent Core 1 from starving other tasks
  delay(1);
}

// PID Preference Handling for ESP32/ESP32-C3
void savePIDToPreferences() {
  Preferences prefs;
  prefs.begin("pid_tuning", false);  // false = read-write mode
  
  // Save general PID gains
  prefs.putFloat("KP", KP);
  prefs.putFloat("KI", KI);
  prefs.putFloat("KD", KD);
  
  // Save Pitch PID gains
  prefs.putFloat("KP_Pitch", KP_Pitch);
  prefs.putFloat("KI_Pitch", KI_Pitch);
  prefs.putFloat("KD_Pitch", KD_Pitch);
  
  // Save Roll PID gains
  prefs.putFloat("KP_Roll", KP_Roll);
  prefs.putFloat("KI_Roll", KI_Roll);
  prefs.putFloat("KD_Roll", KD_Roll);
  
  // Save Yaw PID gains
  prefs.putFloat("KP_Yaw", KP_Yaw);
  prefs.putFloat("KI_Yaw", KI_Yaw);
  prefs.putFloat("KD_Yaw", KD_Yaw);

  #if ENABLE_CASCADE_PID
  // Save cascade pitch angle loop gains
  prefs.putFloat("cpa_kp", cascade_pitch_angle_kp);
  prefs.putFloat("cpa_ki", cascade_pitch_angle_ki);
  prefs.putFloat("cpa_kd", cascade_pitch_angle_kd);

  // Save cascade pitch rate loop gains
  prefs.putFloat("cpr_kp", cascade_pitch_rate_kp);
  prefs.putFloat("cpr_ki", cascade_pitch_rate_ki);
  prefs.putFloat("cpr_kd", cascade_pitch_rate_kd);

  // Save cascade roll angle loop gains
  prefs.putFloat("cra_kp", cascade_roll_angle_kp);
  prefs.putFloat("cra_ki", cascade_roll_angle_ki);
  prefs.putFloat("cra_kd", cascade_roll_angle_kd);

  // Save cascade roll rate loop gains
  prefs.putFloat("crr_kp", cascade_roll_rate_kp);
  prefs.putFloat("crr_ki", cascade_roll_rate_ki);
  prefs.putFloat("crr_kd", cascade_roll_rate_kd);
  #endif
  
  prefs.end();
  delay(100);  // Critical: Allow NVS to flush on ESP32-C3
  Serial.println("[OK] PID values saved to NVS preferences");
}

void resetPIDToDefaults() {
  // Reset to default values from config.h
  KP = DEFAULT_KP;
  KI = DEFAULT_KI;
  KD = DEFAULT_KD;
  
  KP_Pitch = DEFAULT_KP;
  KI_Pitch = DEFAULT_KI;
  KD_Pitch = DEFAULT_KD;
  
  KP_Roll = DEFAULT_KP;
  KI_Roll = DEFAULT_KI;
  KD_Roll = DEFAULT_KD;
  
  KP_Yaw = DEFAULT_KP;
  KI_Yaw = DEFAULT_KI;
  KD_Yaw = DEFAULT_KD;
  
  yaw_rate_target = 0.0f;
  pitch_rate_target = 0.0f;
  roll_rate_target = 0.0f;

  #if ENABLE_CASCADE_PID
  // Reset cascade gains to compile-time defaults
  cascade_pitch_angle_kp = CASCADE_PITCH_ANGLE_KP;
  cascade_pitch_angle_ki = CASCADE_PITCH_ANGLE_KI;
  cascade_pitch_angle_kd = CASCADE_PITCH_ANGLE_KD;

  cascade_pitch_rate_kp = CASCADE_PITCH_RATE_KP;
  cascade_pitch_rate_ki = CASCADE_PITCH_RATE_KI;
  cascade_pitch_rate_kd = CASCADE_PITCH_RATE_KD;

  cascade_roll_angle_kp = CASCADE_ROLL_ANGLE_KP;
  cascade_roll_angle_ki = CASCADE_ROLL_ANGLE_KI;
  cascade_roll_angle_kd = CASCADE_ROLL_ANGLE_KD;

  cascade_roll_rate_kp = CASCADE_ROLL_RATE_KP;
  cascade_roll_rate_ki = CASCADE_ROLL_RATE_KI;
  cascade_roll_rate_kd = CASCADE_ROLL_RATE_KD;
  #endif
  
  // Save defaults to preferences
  savePIDToPreferences();
  delay(50);  // Extra safety delay for ESP32-C3
  
  Serial.println("[OK] PID values reset to defaults and saved");
}

void loadPIDFromPreferences() {
  Preferences prefs;
  prefs.begin("pid_tuning", true);  // true = read-only mode
  
  // Load general PID gains with defaults
  KP = prefs.getFloat("KP", DEFAULT_KP);
  KI = prefs.getFloat("KI", DEFAULT_KI);
  KD = prefs.getFloat("KD", DEFAULT_KD);
  
  // Load Pitch PID gains with defaults
  KP_Pitch = prefs.getFloat("KP_Pitch", DEFAULT_KP);
  KI_Pitch = prefs.getFloat("KI_Pitch", DEFAULT_KI);
  KD_Pitch = prefs.getFloat("KD_Pitch", DEFAULT_KD);
  
  // Load Roll PID gains with defaults
  KP_Roll = prefs.getFloat("KP_Roll", DEFAULT_KP);
  KI_Roll = prefs.getFloat("KI_Roll", DEFAULT_KI);
  KD_Roll = prefs.getFloat("KD_Roll", DEFAULT_KD);
  
  // Load Yaw PID gains with defaults
  KP_Yaw = prefs.getFloat("KP_Yaw", DEFAULT_KP);
  KI_Yaw = prefs.getFloat("KI_Yaw", DEFAULT_KI);
  KD_Yaw = prefs.getFloat("KD_Yaw", DEFAULT_KD);

  #if ENABLE_CASCADE_PID
  // Load cascade pitch angle loop gains
  cascade_pitch_angle_kp = prefs.getFloat("cpa_kp", CASCADE_PITCH_ANGLE_KP);
  cascade_pitch_angle_ki = prefs.getFloat("cpa_ki", CASCADE_PITCH_ANGLE_KI);
  cascade_pitch_angle_kd = prefs.getFloat("cpa_kd", CASCADE_PITCH_ANGLE_KD);

  // Load cascade pitch rate loop gains
  cascade_pitch_rate_kp = prefs.getFloat("cpr_kp", CASCADE_PITCH_RATE_KP);
  cascade_pitch_rate_ki = prefs.getFloat("cpr_ki", CASCADE_PITCH_RATE_KI);
  cascade_pitch_rate_kd = prefs.getFloat("cpr_kd", CASCADE_PITCH_RATE_KD);

  // Load cascade roll angle loop gains
  cascade_roll_angle_kp = prefs.getFloat("cra_kp", CASCADE_ROLL_ANGLE_KP);
  cascade_roll_angle_ki = prefs.getFloat("cra_ki", CASCADE_ROLL_ANGLE_KI);
  cascade_roll_angle_kd = prefs.getFloat("cra_kd", CASCADE_ROLL_ANGLE_KD);

  // Load cascade roll rate loop gains
  cascade_roll_rate_kp = prefs.getFloat("crr_kp", CASCADE_ROLL_RATE_KP);
  cascade_roll_rate_ki = prefs.getFloat("crr_ki", CASCADE_ROLL_RATE_KI);
  cascade_roll_rate_kd = prefs.getFloat("crr_kd", CASCADE_ROLL_RATE_KD);
  #endif
  
  prefs.end();
  Serial.println("[OK] PID values loaded from NVS preferences");
}

// ===== MPU INITIALIZATION RETRY (Recovery Function) =====
void retryMPUInitialization() {
  Serial.println("[INFO] Attempting to retry MPU initialization...");
  
  // Re-initialize I2C bus
  Wire.begin(I2C_SDA, I2C_SCL);
  delay(100);
  
  // Attempt to re-initialize MPU object
  if (mpu.initialize()) {
    mpuInitialized = true;
    Serial.println("[OK] MPU successfully re-initialized");
    filterInitialized = false;  // Reset filter to warm up from next reading
    Serial.println("[INFO] Filter state reset - will warm up from next reading");
  } else {
    Serial.println("[ERROR] MPU re-initialization failed - check sensor connection");
    mpuInitialized = false;
  }
}

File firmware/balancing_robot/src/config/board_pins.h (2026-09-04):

#ifndef BOARD_PINS_H
#define BOARD_PINS_H

// ===== BOARD PIN STORE =====
// No user-editable lines here. The active board is chosen in settings.h
// via ACTIVE_BOARD. This file only stores the per-board profiles.

// Board IDs (match ACTIVE_BOARD values in settings.h)
#define BOARD_PROFILE_ESP32 1
#define BOARD_PROFILE_ESP32C3 2
#define BOARD_PROFILE_ESP32S3 3

// Compatibility board macros
#if ACTIVE_BOARD == BOARD_PROFILE_ESP32
  #define BOARD_ESP32
#elif ACTIVE_BOARD == BOARD_PROFILE_ESP32C3
  #define BOARD_ESP32C3
#elif ACTIVE_BOARD == BOARD_PROFILE_ESP32S3
  #define BOARD_ESP32S3
#else
  #error "Invalid ACTIVE_BOARD in settings.h. Use 1, 2, or 3."
#endif

#if defined(BOARD_ESP32)
  #define PWM_FREQ 19000    //   ESP32 PWM frequency in Hz
  #define PWM_RES 12        // PWM resolution (12-bit = 0-4095)
  #define PWM_MAX 4095      // Maximum PWM value
  #define MOTOR_MIN_PWM 2000 // Minimum motor PWM duty (0-4095) - prevents motor from stalling

  // Status LED: WS2812 addressable RGB on GPIO22 (NOT a plain HIGH/LOW LED)
  #define LOW_VOLTAGE_LED_PIN 22
  #define STATUS_LED_RGB 1
  #define LED_ON_R 0
  #define LED_ON_G 64
  #define LED_ON_B 0      // dim green = ON / connected
  #define LED_BLINK_R 64
  #define LED_BLINK_G 0
  #define LED_BLINK_B 0   // dim red = low-battery blink
  #define LED_ON_LEVEL LOW   // unused in RGB mode, kept for compatibility
  #define LED_OFF_LEVEL HIGH

  // Balancing robot motor driver pins (L298N-style)
  #define ENA 25
  #define IN1 26
  #define IN2 27
  #define ENB 14
  #define IN3 12
  #define IN4 13

  // I2C pins
  
  #define I2C_SDA 23
  #define I2C_SCL 19

  // ADC battery pin
  #define BATTERY_PIN 34
  #define BATTERY_R_UPPER_OHM 100000.0f
  #define BATTERY_R_LOWER_OHM 82000.0f
  #define BATTERY_CALIBRATION_SCALE 0.9957f
  #define BATTERY_DIVIDER_RATIO ((((BATTERY_R_UPPER_OHM + BATTERY_R_LOWER_OHM) / BATTERY_R_LOWER_OHM)) * BATTERY_CALIBRATION_SCALE)
  #define ADC_MAX 4095
  #define ADC_REF_VOLTAGE 3.3f
  #define BATTERY_SAMPLE_SIZE 8
  #define BATTERY_GLITCH_REJECT_V 0.25f

  // SPI pins (if SPI sensor selected)
  #define IMU_SPI_SCK_PIN 18
  #define IMU_SPI_MOSI_PIN 23
  #define IMU_SPI_MISO_PIN 19
  #define IMU_SPI_CS_PIN 5

#elif defined(BOARD_ESP32C3)
  #define PWM_FREQ 9000     // ESP32-C3 PWM frequency in Hz
  #define PWM_RES 12        // PWM resolution (12-bit = 0-4095)
  #define PWM_MAX 4095      // Maximum PWM value
  #define MOTOR_MIN_PWM 2000 // Minimum motor PWM duty (0-4095) - prevents motor from stalling


  // Status LED: WS2812 addressable RGB on GPIO8 (NOT a plain HIGH/LOW LED)
  #define LOW_VOLTAGE_LED_PIN 8
  #define STATUS_LED_RGB 1
  #define LED_ON_R 0
  #define LED_ON_G 64
  #define LED_ON_B 0      // dim green = ON / connected
  #define LED_BLINK_R 64
  #define LED_BLINK_G 0
  #define LED_BLINK_B 0   // dim red = low-battery blink
  #define LED_ON_LEVEL HIGH   // unused in RGB mode, kept for compatibility
  #define LED_OFF_LEVEL LOW

  // Balancing robot motor driver pins (adjust to your wiring)
  #define ENA 3
  #define IN1 4
  #define IN2 5
  #define ENB 10
  #define IN3 6
  #define IN4 7

  // I2C pins
  #define I2C_SDA 0
  #define I2C_SCL 1
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

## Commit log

2026-09-03 Initial commit: ESP32 balancing robot (multi-filter control study)
    [chassis.stl, n20 motor mount.stl]
2026-09-03 chore: move timing.h + i2c_scan.h into utils/ (Phase 2, folder 1)
2026-09-03 chore: move config.h + board.h + sensor.h into config/ (Phase 2, folder 2)
2026-09-03 chore: move IMU drivers + calibration.h into sensors/ (Phase 2, folder 3)
2026-09-03 chore: move 6 filters + selector into filters/ (Phase 2, folder 4)
2026-09-03 chore: move pid + cascade + motor into control/ (Phase 2, folder 5)
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2026-09-03 chore: delete dead altitude-hold, barometer, and stale pin leftovers (Phase 2)
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2026-09-03 chore: split kalman filter into .h/.cpp (Phase 3, filters 1/6)
2026-09-03 chore: split mahony filter into .h/.cpp (Phase 3, filters 2/6)
2026-09-03 chore: split complementary filters into .h/.cpp (Phase 3, filters 3-4/6)
2026-09-03 chore: split madgwick filter into .h/.cpp (Phase 3, filters 5/6)
2026-09-03 chore: split ekf filter into .h/.cpp (Phase 3, filters 6/6)
2026-09-03 chore: split motor + pid into .h/.cpp (Phase 3, control 1-2/3)
2026-09-03 chore: split cascade pid into .h/.cpp (Phase 3, control 3/3)
2026-09-03 chore: split calibration + lift BatteryState to shared header (comms prereq)
2026-09-03 chore: conditional filter includes in .ino (Phase 3 complete)
2026-09-03 chore: split IMU drivers into .h/.cpp (Phase 4, sensors)
2026-09-03 chore: move PID prefs into system/prefs (Phase 5, 1/5)
2026-09-03 chore: move battery voltage+monitoring into system/battery (Phase 5, 2/5)
2026-09-03 chore: move vehicle motor fns into control/motor_control (Phase 5, 3/5)
2026-09-03 chore: move IMU object+init into system/imu (Phase 5, 4/5)
2026-09-03 Revert "chore: move control loop into system/control_task (Phase 5, 5/5)"
    This reverts commit 52b2e1e39b3d6459e8d938d09223556170437cfe.
    [control_task.cpp]
2026-09-03 Revert "chore: move IMU object+init into system/imu (Phase 5, 4/5)"
    This reverts commit 2f830e708cd5547083d55e9db2b2dd974b535669.
    [balancing_robot.ino, imu.cpp]
2026-09-04 Reapply "chore: move IMU object+init into system/imu (Phase 5, 4/5)"
    This reverts commit 44b9687f460aa8800ba47aef5c1a80869f17dba1.
    [balancing_robot.ino, imu.cpp]
2026-09-04 chore: keep control loop in .ino, IMU only in system/imu (Phase 5, 4/5 only)
2026-09-04 fix: single-source DEFAULT_KP/KI/KD (8/0.2/5) in config.h, drop dead motor-test vars
    [balancing_robot.ino, calibration.h]
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2026-09-04 chore: move loop telemetry block into printTelemetryStatus (cleanup 2)
2026-09-04 chore: split PID-tuning CLI into serial_pid_commands (cleanup 4)
2026-09-04 chore: split calibration into gyro/accel flow files (cleanup 5)
2026-09-04 chore: move calibration state+bias defs to calibration.cpp (move 1)
2026-09-04 chore: move PID gains+state defs to pid_controller.cpp (move 2)
2026-09-04 chore: move pitch/roll rate targets to cascade controller (move 3)
2026-09-04 chore: move motor/arm/throttle defs to motor_control.cpp (move 4)
2026-09-04 chore: move battery monitor defs to battery.cpp (move 5)
2026-09-04 chore: move throttle-gate/prefs/monitor-flag defs to owners (move 7)
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2026-09-04 feat: RGB status LED support for ESP32-C3 built-in WS2812
2026-09-04 feat: RGB status LED on ESP32-S3 built-in WS2812 (GPIO48)
2026-09-04 feat: RGB status LED on ESP32 classic profile (GPIO22)
2026-09-04 feat: serial CLI for status LED (led test/on/off/rgb)
2026-09-04 chore: rename config ships to board_pins/imu_select, selectors move out
2026-09-04 feat: enable test_motor wheel spin test (LEFT→LEFTrev→RIGHT→RIGHTrev, 20%, 2s)
2026-09-04 feat: motor test at 60pct PWM (above stall floor)
    [motor_control.cpp, serial_commands.cpp]
2026-09-04 fix: WS joystick drives angle setpoints + yaw rate (was speed-only/dead)
    pitch/roll now set pitch_setpoint/roll_setpoint for the
    single/dual PID path, yaw sets yaw_rate_target which
    updateYawPID actually reads; speed setpoints kept for cascade
    [websocket_handler.cpp]
2026-09-04 fix: negate WS pitch input so forward stick drives forward
    [websocket_handler.cpp]
2026-09-04 feat: WS stick direction flags in settings.h (pitch/roll/yaw invert)
    [settings.h, websocket_handler.cpp]
2026-09-04 chore: drop WS_* invert flags, stick orientation lives in UI only
    [settings.h, websocket_handler.cpp]
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2026-09-04 chore: retheme to NEBULA VOID — zero corners, black palette, Space Grotesk + JetBrains Mono, bottom tab bar mobile
2026-09-04 fix: playwright+vision loop — square stick instrument, control grid, working tab bar, aligned pills
2026-09-04 feat: USB serial transport alongside WS — same stick, same telemetry, CLI translation
2026-09-04 feat: serial ↔ UI full sync — load JSON + telemetry + PID/trim/calib
    - firmware: buildStateJson()+printStateJsonSerial() shares WS state JSON over USB serial; load now answers over serial so LINK=SERIAL autofills PID/trim/bias inputs
    - UI/link: onSerialLine parses JSON state replies; connectSerial auto-enables LOOP + load on open; deviceSend routes all features byte-identical (pid_tune, trim, calib, reset, load) to CLI (pitch_p/trim_pitch/calibrate_gyro/save/abort/reset_pid/load)
    - verified: arduino-cli esp32c3 compiles 1201959/91%, node --check link+panels OK, wifi_ota.h creds left uncommitted
    [serial_commands.cpp, websocket_handler.cpp]
2026-09-04 ui: merge GRAPH into STATUS — telemetry, instruments, graphs, console in one tab
2026-09-04 ui: monotone relevant sidebar icons — grid status, wave PID, text-presentation wrench
2026-09-04 ui: VISWA rebrand + mono SVG icons + readonly arm pill + fitted square stick
2026-09-04 ui: brand into sidebar, battery+arm left, fitted control tab
2026-09-04 ui: Claude-style expanded sidebar — brand on top, hamburger + panel toggle
2026-09-04 ui: single-row sidebar menu — hamburger collapsed, brand + panel toggle expanded
2026-09-04 ui: quality loop pass — scroll fix, mono icons, fitted stick, header, compass, battery unknown-gray
2026-09-04 ui: premium pass — corner ticks, type hierarchy, hold-to-arm, offline gate, dot grid, STATUS viz (KPI/horizon/motors), JARVIS boot + sweep ring
2026-09-04 ui: gate single centered column, full-width buttons, one-line subtitle
2026-09-04 ui: NO LINK arm button reopens the link gate
2026-09-04 fix: swallow release click after hold-to-arm so it stays armed
2026-09-04 ui: balancing yaw deadzone +-20deg about fore-aft axis + visible rails
2026-09-04 ui: tunable yaw deadzone slider in SETUP (default 10deg, saved locally)
2026-09-04 ui: modern thumbstick knob — domed nub, deflection sector, glow, crescent highlight
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2026-09-04 ui: minimalist stick — single ring, cardinal dots, arc indicator, small nub
2026-09-04 fix: held drags track outside the border, only release recenters
2026-09-04 fix: mobile control tab never scrolls — fluid stick fit, drop dead padding
2026-09-04 feat: yaw rate sensitivity slider 20-200 deg/s default 100 in STICK RANGE
2026-09-05 tune: firmware pitch hard cap 15deg, UI maxAngle slider 5-15 default 10
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2026-09-05 Remove legacy single-PID KP/KI/KD: updateSinglePID, set p/i/d CLI, NVS keys, arm pidIntegral now pitch
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2026-09-05 Tilt guard 5 to 15deg, flip pitch input sign
    [settings.h]
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2026-09-06 Runtime board pins: NVS overrides + CLI (pins show, pin set, pins save/reset)
    [MPU6500_SPI_Custom.cpp, balancing_robot.ino, battery.cpp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]
2026-09-06 Runtime WiFi creds: NVS overrides + CLI (wifi show/set/save/reset), passwords masked
    [balancing_robot.ino, serial_commands.cpp, wifi_creds.cpp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]
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2026-09-06 Add reboot/restart command to serial CLI and WebSocket (disarms motors first)
    [serial_commands.cpp, websocket_handler.cpp]
2026-09-06 Drive motor pins LOW at setup start to stop boot-time spin (GPIO-only, LEDC init stays later)
2026-09-06 Light status LED on WebSocket connect, same as ESP-NOW link (works on USB power too)
2026-09-06 Retry IMU probe 3x at boot for slow rails/loose wiring
    [imu.cpp]
2026-09-06 Run battery/link-LED monitor in loop (was dead code, WS+ESPNOW LEDs never drove)
2026-09-06 Accept pin -1 as unused for SPI/BAT/LED (CLI, SPI probe skip, LED+ADC guards)
    [MPU6500_SPI_Custom.cpp, battery.cpp, pins_live.cpp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]
2026-09-06 Pin set auto-saves to NVS, add debug nvs dump, drop drone t-throttle CLI
2026-09-06 Split debug into motor/imu/led toggles, drop test_motor led-cli and battery noise
    [balancing_robot.ino, battery.cpp, control_task.cpp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]
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2026-09-07 Setup finish: Enter reboots, fix dead ST_DONE from early finish
    [serial_commands.cpp]
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2026-10-09 Mobile UI pass + wireless serial console
    - One-line phone header: battery + link pill + 44px fullscreen (ARM/BALANCING pills gone)
    - Throttle leftovers removed (readout, THR KPI, telemetry row); wire value kept
    - Angle graph: y locked +-20, x tick labels hidden, height follows CSS box
    - Fullscreen hole-punch clearance; landscape side-by-side control + right-packed pill
    - Portrait CONTROL stretches to tab bar; console input (USB raw / WS cli) + tee firmware bridge
    - Console readable: no timestamps, word-boundary wrap, bold echoes
    [calibration.cpp, comms_mode.cpp, controller.ino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]
